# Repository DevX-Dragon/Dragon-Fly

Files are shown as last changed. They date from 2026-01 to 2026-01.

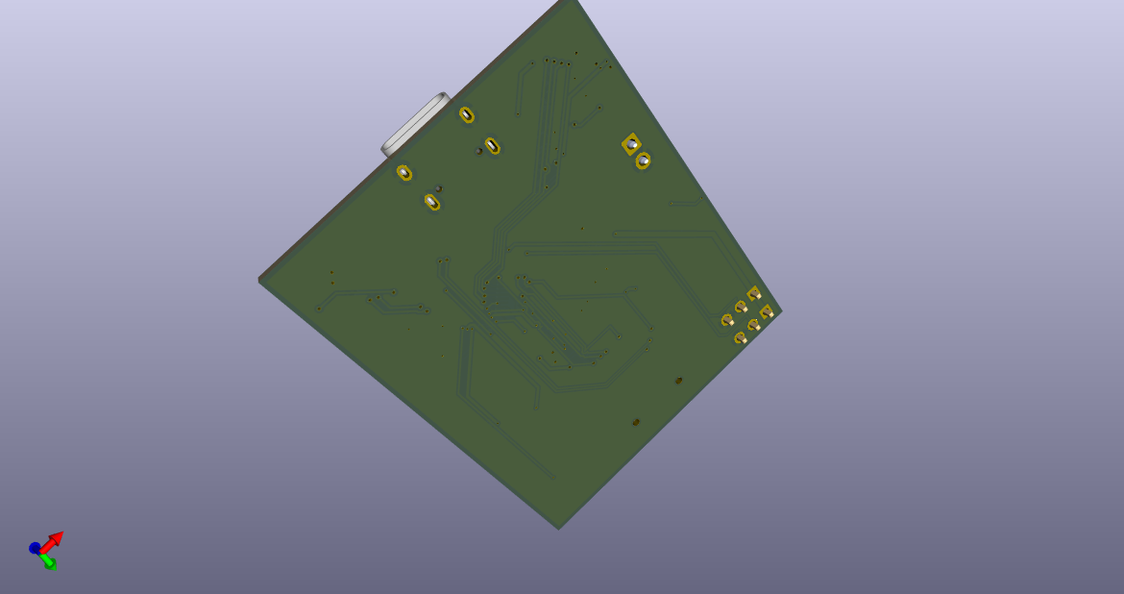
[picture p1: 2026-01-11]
Photos/Back.png

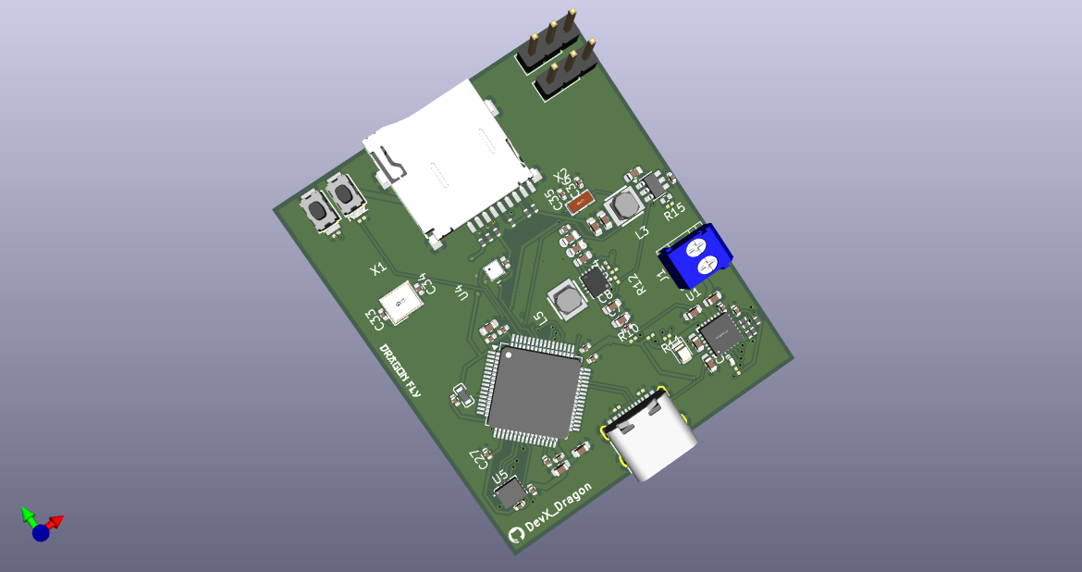
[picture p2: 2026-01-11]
Photos/Flight Controller 1 .png

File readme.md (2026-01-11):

# Dragon Fly Rocket Controller
High-Performance STM32F7-based Flight Controller for Rockets & Drones

Black Render
eye-level

## Project Overview
This project is a custom, lightweight flight controller designed around the STM32F722RET6 MCU. It features advanced power regulation for wide-voltage battery inputs and high-precision sensing for rocket/drone telemetry.

## Core Specifications
MCU: STM32F722RET6 (216MHz ARM Cortex-M7)

**IMU:** TDK InvenSense ICM-42688-P (High-precision 6-axis)

**Barometer:** BMP580 (Precision altitude sensing)

**Power Supply:** TPS63070 Buck-Boost (Output: 5V @ 2A)

**Logic Voltage:** 3.3V (via LDO)

## Schematics and PCB
Schematics Layout
PCB Layout

## 🤝 Contributing
Contributions are welcome! If you find a bug in the design or have a suggestion for firmware implementation, please open an Issue or submit a Pull Request.

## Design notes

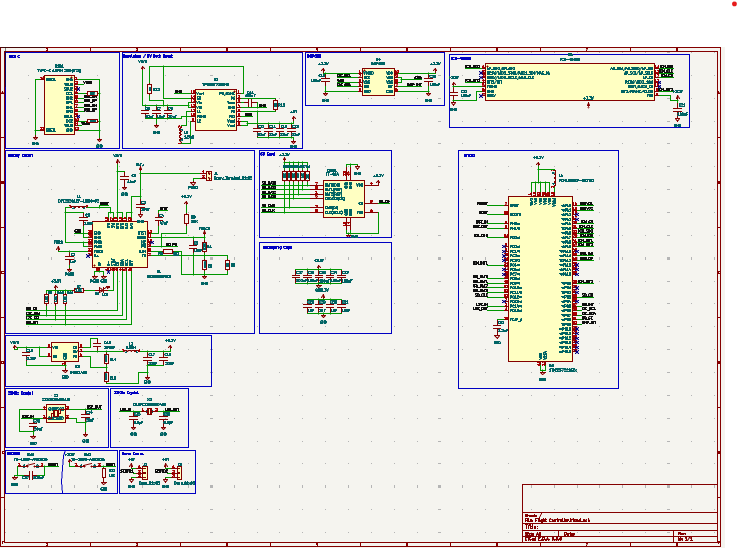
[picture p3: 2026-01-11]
Photos/Schematics Layout.png

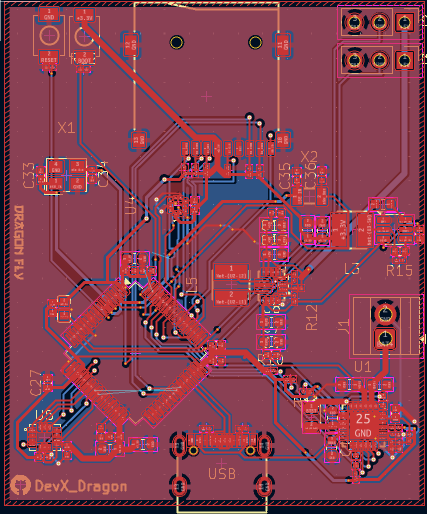
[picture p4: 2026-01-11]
Photos/PCB Layout.png

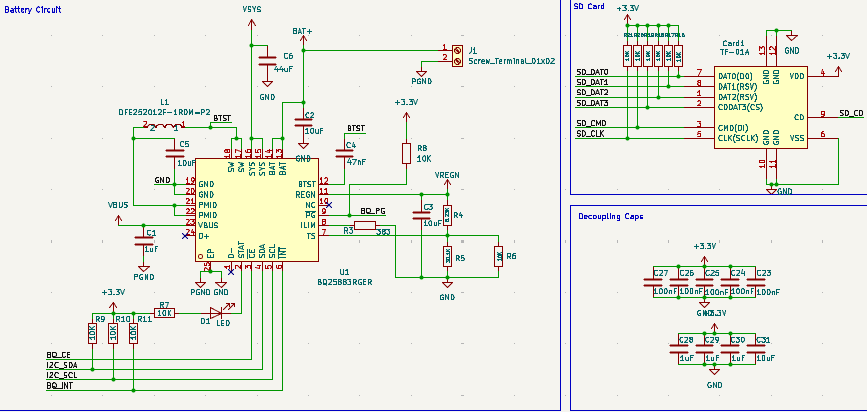
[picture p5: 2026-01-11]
Photos/Battery Circuit, SD card, Decup caps.png

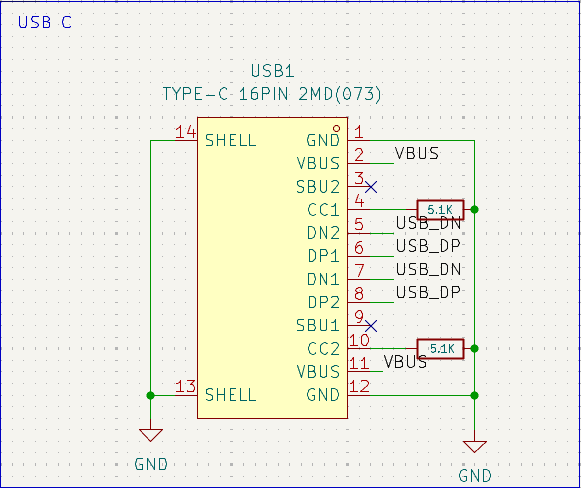
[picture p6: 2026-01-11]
Photos/USB C.png

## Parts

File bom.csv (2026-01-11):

Designator | Footprint | Quantity | Value | LCSC Part #
C1, C29, C30 | 0603 | 3 | 1uF
C10, C11, C13, C17, C18 | 0603 | 5 | 22uF
C12 | 0402 | 1 | 22uF
C14, C37 | 0201 | 2 | 100nF
C15 | 0603 | 1 | 100nF
C16, C32 | 0402 | 2 | 2.2uF
C19, C20, C21, C22, C23, C24, C25, C26, C27 | 0402 | 9 | 100nF
C2, C31, C5, C7, C8 | 0603 | 5 | 10uF
C28 | 0402 | 1 | 1uF
C3, C9 | 0402 | 2 | 10uF
C33, C34 | 0402 | 2 | 20pF
C35, C36 | 0402 | 2 | 6.8pF
C4 | 0402 | 1 | 47nF
C6 | 0603 | 1 | 44uF
CARD1 | TF-SMD_TF-01A | 1 | TF-01A | C91145
D1 | 0402 | 1 | LED
J1 | TerminalBlock_Xinya_XY308-2.54-2P_1x02_P2.54mm_Horizontal | 1 | Screw_Terminal_01x02
J2, J3 | PinHeader_1x03_P2.54mm_Vertical | 2 | Conn_01x03
L1 | 0805 | 1 | DFE252012F-1R0M=P2 | C435392
L3 | IND-SMD_L3.0-W3.0 | 1 | 5.6uH | C435392
L4 | L0603 | 1 | FCM1608KF-601T03 | C141723
L5 | IND-SMD_L3.0-W3.0 | 1 | 1.5uH | C18236327
R1, R2 | 0201 | 2 | 5.1K
R10, R11, R12, R13, R16, R17, R18, R19, R20, R21, R22, R6, R7, R8, R9 | 0201 | 15 | 10K
R14 | 0402 | 1 | 100K
R15 | 0201 | 1 | 22.1K
R3 | 0201 | 1 | 383
R4 | 0201 | 1 | 5.23K
R5 | 0201 | 1 | 30.1K
SW1, SW2 | SW-SMD_L3.9-W3.0-P4.45 | 2 | TS-1088-AR02016 | C720477
U1 | VFQFPN-24_L4.0-W4.0-P0.50-BL-EP2.8 | 1 | BQ25883RGER | C544362
U2 | VQFN-HR-15_L3.0-W2.5-P0.50-BL_TPS63070RNMR | 1 | TPS63070RNMR | C109322
U3 | SOT-23-6 | 1 | LMR51430
U4 | LGA-10_L2.0-W2.0-P0.50-TL_BMP580 | 1 | BMP580 | C22391138
U5 | LGA-14_L3.0-W2.5-P0.50-TL | 1 | ICM-45686 | C22459454
U6 | LQFP-64_10x10mm_P0.5mm | 1 | STM32F722RETx
USB | USB-C-SMD_TYPE-C-6PIN-2MD-073 | 1 | TYPE-C 16PIN 2MD(073) | C2765186
X1 | CRYSTAL-SMD_4P-L3.2-W2.5-BL | 1 | X322525MOB4SI | C9006
X2 | FC-135R_L3.2-W1.5 | 1 | Q13FC1350000400 | C32346

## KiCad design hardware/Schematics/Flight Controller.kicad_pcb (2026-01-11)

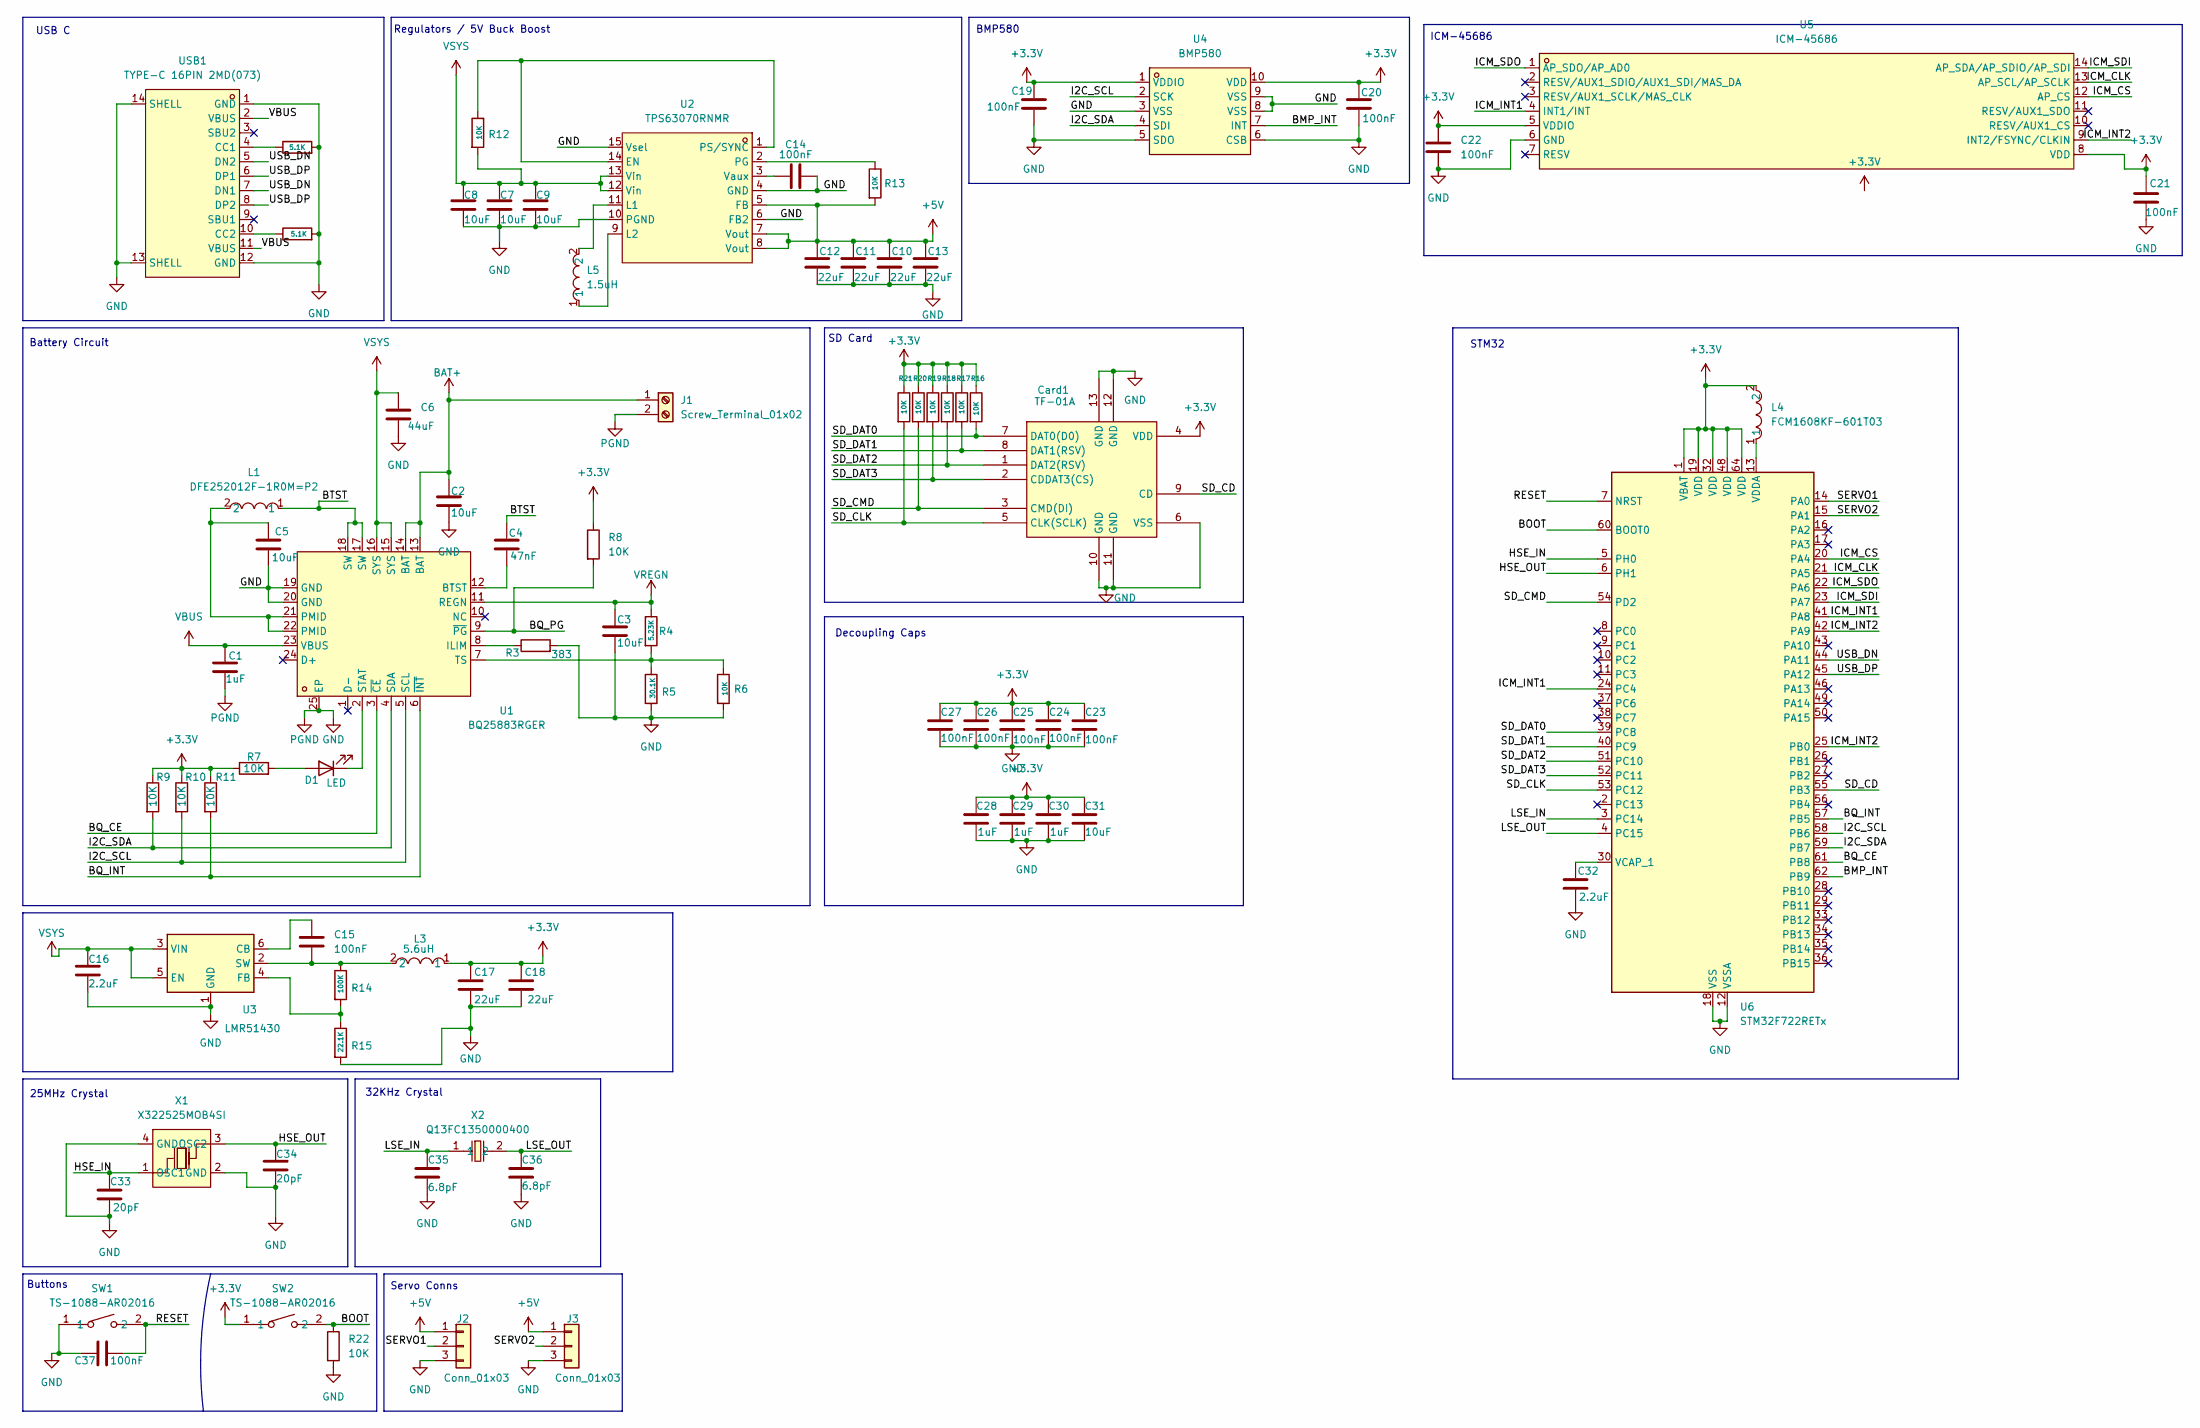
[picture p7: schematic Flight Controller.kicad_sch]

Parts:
C1, C28, C29, C30: 1uF; C_0603_1608Metric
C2, C3, C5, C7, C8, C9, C31: 10uF; C_0603_1608Metric
C4: 47nF; C_0603_1608Metric
C6: 44uF; C_0603_1608Metric
C10, C11, C12, C13, C17, C18: 22uF; C_0603_1608Metric
C14, C15: 100nF; C_0603_1608Metric
C16, C32: 2.2uF; C_0603_1608Metric
C19, C20, C21, C22, C23, C24, C25, C26, C27, C37: 100nF; C_0402_1005Metric
C33, C34: 20pF; C_0402_1005Metric
C35, C36: 6.8pF; C_0402_1005Metric
Card1: TF-01A; TF-SMD_TF-01A; LCSC Part C91145
D1: LED; LED_0402_1005Metric
J1: Screw_Terminal_01x02; TerminalBlock_Xinya_XY308-2.54-2P_1x02_P2.54mm_Horizontal
J2, J3: Conn_01x03; PinHeader_2x03_P2.54mm_Vertical
L1: DFE252012F-1R0M=P2; LED_0402_1005Metric; LCSC Part C435392
L3: 5.6uH; L2520; LCSC Part C435392
L4: FCM1608KF-601T03; L0603; LCSC Part C141723
L5: 1.5uH; IND-SMD_L3.0-W3.0; LCSC Part C18236327
R1, R2: 5.1K; R_0201_0603Metric
R3: 383; R_0201_0603Metric
R4: 5.23K; R_0201_0603Metric
R5: 30.1K; R_0201_0603Metric
R6, R7, R8, R9, R10, R11, R12, R13, R16, R17, R18, R19, R20, R21, R22: 10K; R_0201_0603Metric
R14: 100K; R_0402_1005Metric
R15: 22.1K; R_0201_0603Metric
SW1, SW2: TS-1088-AR02016; SW-SMD_L3.9-W3.0-P4.45; LCSC Part C720477
U1: BQ25883RGER; VFQFPN-24_L4.0-W4.0-P0.50-BL-EP2.8; LCSC Part C544362
U2: TPS63070RNMR; VQFN-HR-15_L3.0-W2.5-P0.50-BL_TPS63070RNMR; LCSC Part C109322
U3: LMR51430; SOT-23-6
U4: BMP580; LGA-10_L2.0-W2.0-P0.50-TL_BMP580; LCSC Part C22391138
U5: ICM-45686; LGA-14_L3.0-W2.5-P0.50-TL; LCSC Part C22459454
U6: STM32F722RETx; LQFP-64_10x10mm_P0.5mm
USB1: TYPE-C 16PIN 2MD(073); USB-C-SMD_TYPE-C-6PIN-2MD-073; LCSC Part C2765186
X1: X322525MOB4SI; CRYSTAL-SMD_4P-L3.2-W2.5-BL; LCSC Part C9006
X2: Q13FC1350000400; FC-135R_L3.2-W1.5; LCSC Part C32346

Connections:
+3.3V: C17.1, C18.1, C19.1, C20.1, C21.1, C22.1, C23.1, C24.1, C25.1, C26.1, C27.1, C28.1, C29.1, C30.1, C31.1, Card1.4 (VDD), L3.1, L4.2, R7.1, R8.1, R9.1, R10.1, R11.1, R16.1, R17.1, R18.1, R19.1, R20.1, R21.1, SW2.1, U4.1 (VDDIO), U4.10 (VDD), U5.5 (VDDIO), U5.8 (VDD), U6.1 (VBAT), U6.19 (VDD), U6.32 (VDD), U6.48 (VDD), U6.64 (VDD)
+5V: C10.1, C11.1, C12.1, C13.1, J2.1, J3.1, R13.2, U2.5 (FB), U2.7 (Vout), U2.8 (Vout)
/BMP_INT: U4.7 (INT), U6.62 (PB9)
/BOOT: R22.1, SW2.2, U6.60 (BOOT0)
/BQ_CE: U1.3 (~CE), U6.61 (PB8)
/BQ_INT: R11.2, U1.6 (~INT), U6.57 (PB5)
/BQ_PG: R8.2, U1.9 (~PG)
/BTST: C4.1, L1.1, U1.17 (SW), U1.18 (SW)
/HSE_IN: C33.1, U6.5 (PH0), X1.1 (OSC1)
/HSE_OUT: C34.1, U6.6 (PH1), X1.3 (OSC2)
/I2C_SCL: R10.2, U1.5 (SCL), U4.2 (SCK), U6.58 (PB6)
/I2C_SDA: R9.2, U1.4 (SDA), U4.4 (SDI), U6.59 (PB7)
/ICM_CLK: U5.13 (AP_SCL/AP_SCLK), U6.21 (PA5)
/ICM_CS: U5.12 (AP_CS), U6.20 (PA4)
/ICM_INT1: U5.4 (INT1/INT), U6.24 (PC4), U6.41 (PA8)
/ICM_INT2: U5.9 (INT2/FSYNC/CLKIN), U6.25 (PB0), U6.42 (PA9)
/ICM_SDI: U5.14 (AP_SDA/AP_SDIO/AP_SDI), U6.23 (PA7)
/ICM_SDO: U5.1 (AP_SDO/AP_AD0), U6.22 (PA6)
/LSE_IN: C35.1, U6.3 (PC14), X2.1
/LSE_OUT: C36.1, U6.4 (PC15), X2.2
/RESET: C37.2, SW1.2, U6.7 (NRST)
/SD_CD: Card1.9 (CD), U6.55 (PB3)
/SD_CLK: Card1.5 (CLK(SCLK)), R21.2, U6.53 (PC12)
/SD_CMD: Card1.3 (CMD(DI)), R20.2, U6.54 (PD2)
/SD_DAT0: Card1.7 (DAT0(D0)), R16.2, U6.39 (PC8)
/SD_DAT1: Card1.8 (DAT1(RSV)), R17.2, U6.40 (PC9)
/SD_DAT2: Card1.1 (DAT2(RSV)), R18.2, U6.51 (PC10)
/SD_DAT3: Card1.2 (CDDAT3(CS)), R19.2, U6.52 (PC11)
/SERVO1: J2.2, U6.14 (PA0)
/SERVO2: J3.2, U6.15 (PA1)
/USB_DN: U6.44 (PA11), USB1.5 (DN2), USB1.7 (DN1); also elsewhere on the board
/USB_DP: U6.45 (PA12), USB1.6 (DP1), USB1.8 (DP2); also elsewhere on the board
BAT+: C2.1, J1.1, U1.13 (BAT), U1.14 (BAT)
GND: C1.2, C2.2, C3.2, C5.2, C6.2, C7.2, C8.2, C9.2, C10.2, C11.2, C12.2, C13.2, C14.2, C16.2, C17.2, C18.2, C19.2, C20.2, C21.2, C22.2, C23.2, C24.2, C25.2, C26.2, C27.2, C28.2, C29.2, C30.2, C31.2, C32.2, C33.2, C34.2, C35.2, C36.2, C37.1, Card1.6 (VSS), Card1.10 (GND), Card1.11 (GND), Card1.12 (GND), Card1.13 (GND), J1.2, J2.3, J3.3, R1.2, R2.2, R3.2, R5.2, R6.2, R15.2, R22.2, SW1.1, U1.19 (GND), U1.20 (GND), U1.25 (EP), U2.4 (GND), U2.6 (FB2), U2.10 (PGND), U2.15 (Vsel), U3.1 (GND), U4.3 (VSS), U4.5 (SDO), U4.6 (CSB), U4.8 (VSS), U4.9 (VSS), U5.6 (GND), U6.12 (VSSA), U6.18 (VSS), U6.31 (VSS), U6.47 (VSS), U6.63 (VSS), USB1.1 (GND), USB1.12 (GND), USB1.13 (SHELL), USB1.14 (SHELL), X1.2 (GND), X1.4 (GND); also elsewhere on the board
unnamed: C5.1, L1.2, U1.21 (PMID), U1.22 (PMID)
unnamed: D1.2 (A), R7.2
unnamed: D1.1 (K), U1.2 (STAT)
unnamed: C4.2, U1.12 (BTST)
unnamed: R3.1, U1.8 (ILIM)
unnamed: R4.2, R5.1, R6.1, U1.7 (TS)
unnamed: R12.1, U2.1 (PS/SYNC), U2.14 (EN)
unnamed: L5.2, U2.11 (L1)
unnamed: L5.1, U2.9 (L2)
unnamed: R13.1, U2.2 (PG)
unnamed: C14.1, U2.3 (Vaux)
unnamed: C15.1, U3.6 (CB)
unnamed: R14.2, R15.1, U3.4 (FB)
unnamed: C15.2, L3.2, R14.1, U3.2 (SW)
unnamed: C32.1, U6.30 (VCAP_1)
unnamed: L4.1, U6.13 (VDDA)
unnamed 50: R1.1, USB1.4 (CC1); also elsewhere on the board
unnamed 51: R2.1, USB1.10 (CC2); also elsewhere on the board
unnamed: USB1.2 (VBUS), USB1.11 (VBUS)
VBUS: C1.1, U1.23 (VBUS); also elsewhere on the board
VREGN: C3.1, R4.1, U1.11 (REGN)
VSYS: C6.1, C7.1, C8.1, C9.1, C16.1, R12.2, U1.15 (SYS), U1.16 (SYS), U2.12 (Vin), U2.13 (Vin), U3.3 (VIN), U3.5 (EN)

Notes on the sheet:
Decoupling Caps
32KHz Crystal
ICM-45686
Battery Circuit
SD Card
BMP580
Regulators / 5V Buck Boost
USB C
Buttons
25MHz Crystal
Servo Conns
STM32

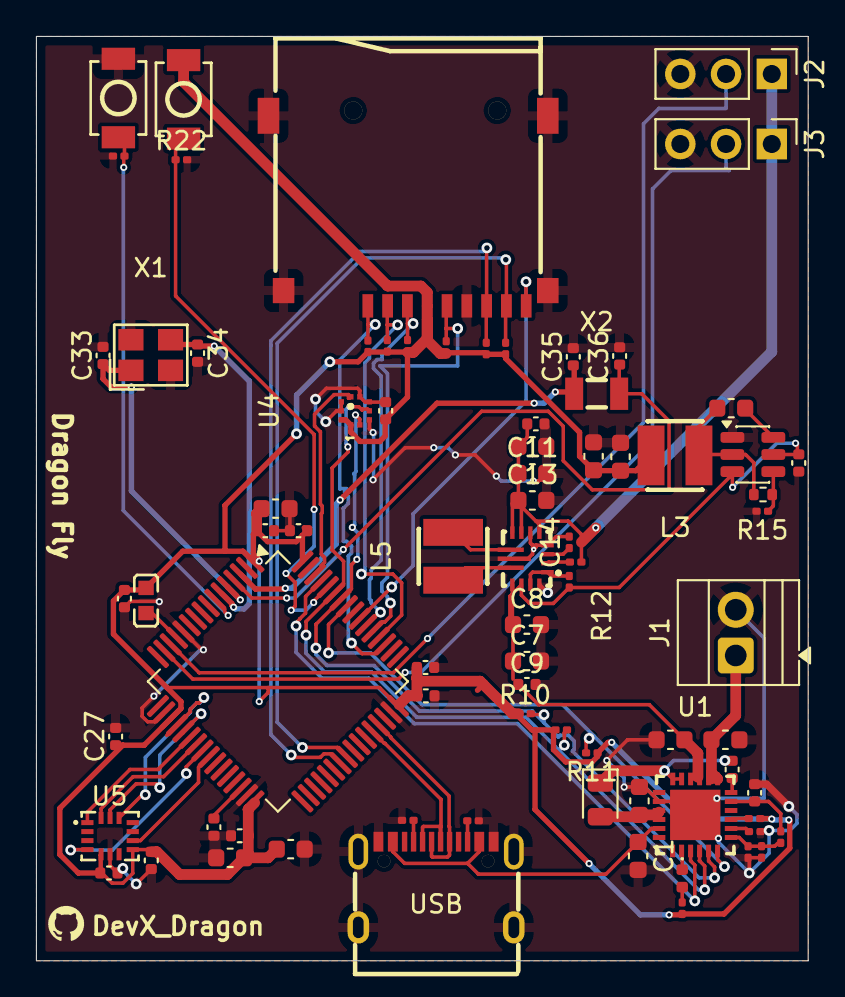
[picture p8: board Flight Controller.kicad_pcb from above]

Board: 2 copper layers, 42.9 x 51.4 mm, 79 parts (0 on the bottom side), 55 nets.

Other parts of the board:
USB: TYPE-C 16PIN 2MD(073); USB-C-SMD_TYPE-C-6PIN-2MD-073

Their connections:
/USB_DN: USB.5 (DN2), USB.7 (DN1); also elsewhere on the board
/USB_DP: USB.6 (DP1), USB.8 (DP2); also elsewhere on the board
GND: USB.1 (GND), USB.12 (GND), USB.13 (SHELL), USB.14 (SHELL); also elsewhere on the board
unnamed 50: USB.4 (CC1); also elsewhere on the board
unnamed 51: USB.10 (CC2); also elsewhere on the board
VBUS: USB.2 (VBUS), USB.11 (VBUS); also elsewhere on the board

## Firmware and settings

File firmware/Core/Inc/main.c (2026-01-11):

/* * PROJECT: Project-X Flight Controller
 * TARGET:  STM32F722RET6 | 216MHz
 * REVISION: 1.0 (Demo for Technical Review)
 */

#include "main.h"
#include <math.h>

/* --- PID GAINS (Tuned for high-speed response) --- */
float Kp = 1.25f, Ki = 0.04f, Kd = 0.12f;
float pitch_error, last_pitch_error, pitch_integral;
float setpoint = 0.0f; // Maintain level flight

/* --- SENSOR DATA --- */
float accel_x, accel_y, accel_z;
float gyro_x, gyro_y, gyro_z;
float filtered_pitch = 0.0f;

/* * STEP 1: SENSOR FUSION 
 * Judges look for this. It combines Accel and Gyro data.
 */
void Sensor_Fusion(float dt) {
    // Calculate pitch from accelerometer (Gravity vector)
    float accel_angle = atan2f(-accel_x, sqrtf(accel_y * accel_y + accel_z * accel_z)) * 57.295f;
    
    // Complementary Filter: 98% Gyro (Fast) + 2% Accel (Stable)
    filtered_pitch = 0.98f * (filtered_pitch + gyro_x * dt) + 0.02f * accel_angle;
}

/* * STEP 2: PID CONTROL 
 * The math that decides how much to move the motors.
 */
float Calculate_Control(float current_val, float dt) {
    pitch_error = setpoint - current_val;
    pitch_integral += pitch_error * dt;
    float derivative = (pitch_error - last_pitch_error) / dt;
    
    last_pitch_error = pitch_error;
    return (Kp * pitch_error) + (Ki * pitch_integral) + (Kd * derivative);
}

int main(void) {
    HAL_Init();
    SystemClock_Config(); // Boost to 216MHz
    
    /* Initialize I/O */
    MX_GPIO_Init();
    MX_SPI1_Init(); // Talk to ICM-42688-P
    MX_TIM2_Init(); // PWM for Motors
    
    /* THE MAIN FLIGHT LOOP (Deterministic 1000Hz) */
    while (1) {
        uint32_t start = HAL_GetTick();

        Read_IMU_Data(&accel_x, &accel_y, &accel_z, &gyro_x, &gyro_y, &gyro_z);
        Sensor_Fusion(0.001f);
        float adjustment = Calculate_Control(filtered_pitch, 0.001f);
        
        Update_Motors(adjustment);

        // Wait until 1ms has passed exactly
        while(HAL_GetTick() - start < 1); 
    }
}
